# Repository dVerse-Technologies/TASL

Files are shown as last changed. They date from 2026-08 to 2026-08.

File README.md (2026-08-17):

# TASL — modular marble-run engineering challenge

A collaborative marble-run built by ~10 teams of senior engineers. A 25 mm
steel ball travels from a common START to a common FINISH through every team's
module. Battery-powered ESP32 nodes watch the ball with IR break-beams, time
it, and report to a server running a live dashboard over an offline Wi-Fi
network.

Alongside the run there is a simulated materials economy: an operator fires
news events from an admin panel, material prices move, a depot kiosk reprices
and a stage projector flashes breaking news — all on four screens that stay in
sync because one server holds the only copy of the state.

Node schematic

---

## Status

| Step | What | State |
|---|---|---|
| 1 | Live dashboard fed by 3 simulated nodes | **done** |
| 2 | Real ESP32s connected over Wi-Fi | **done — 3 nodes reporting** |
| 3 | IR beam circuit built and range-tested | **done — 40 mm gap working** |
| 4 | Battery sensing + RGB status LED | in progress |
| 5 | Two beams per node, real ball velocity | not started |
| 6 | Replicate across 20 nodes | not started |
| 7 | Admin panel, depot prices, stage projector | **done** |

---

## The four screens

One server on the **Admin MiniPC**, four pages, four machines.

| Machine | URL | Shows | Who sees it |
|---|---|---|---|
| Admin MiniPC | `/admin` | Event triggers, pricing, diagnostics | Operator only |
| Depot MiniPC | `/depot` | Live BOM prices, hike badge top right | Participants |
| Stage laptop + projector | `/stage` | Price board, interrupted by news flashes | The room |
| Build-space MiniPC | `/` | Ball location and speed | Participants |

There are no logins. Screens are separated by URL, and the diagnostics that
used to sit behind a wrench icon on the public dashboard now live on `/admin`
only, so participants never see a station misbehaving.

Sync is not a protocol — it is an absence of one. Every page opens the same
WebSocket and renders the same broadcast, so two boards cannot disagree.

**The full event-day guide is
[`docs/EVENT_DAY_SCREENS.md`](docs/EVENT_DAY_SCREENS.md)** — running order,
kiosk-mode commands, what to press when, and what survives a restart.

---

## Quick start

Two terminals, from the repo root.

```bash
python -m pip install -r requirements.txt
```

**Terminal 1 — dashboard server:**

```bash
python run_server.py
```

**Terminal 2 — three simulated nodes (no hardware needed):**

```bash
python sim/run_mocks.py
```

Then open any of the four screens:

| | |
|---|---|
| <http://localhost:8000/admin> | triggers, pricing, diagnostics |
| <http://localhost:8000/depot> | live material prices |
| <http://localhost:8000/stage> | projector — click **CLICK TO ARM** once |
| <http://localhost:8000/> | ball location and speed |

With real hardware, skip terminal 2 and power the nodes instead.

### Before plugging in hardware

```bash
powershell -ExecutionPolicy Bypass -File tools\preflight.ps1
```

macOS (the event-day machine):

```bash
bash tools/preflight.sh
```

Checks the laptop's IP, firewall, network profile, Wi-Fi band and Python deps.
It changes nothing — it prints the commands you need.

---

## Repo map

```
server/          FastAPI server for all four screens
  protocol.py      THE CONTRACT — exact JSON a node sends. Firmware must match.
  store.py         Node state, run state, SQLite logging
  market.py        Prices, news events, the stage flash. Compounding, rounds up.
  diagnostics.py   Fault rules: what's wrong and what to check
  app.py           HTTP + WebSocket endpoints, the four page routes
  static/          All four UIs (plain HTML/CSS/JS, no build step)
    index.html/app.js    ball tracking      → /
    depot.html           material prices    → /depot
    stage.html/stage.js  projector          → /stage
    admin.html/admin.js  operator console   → /admin
    bus.js               shared WebSocket client for the three new screens
    board.js/board.css   the price board, shared by depot and stage
    media/               drop breaking-news .mp4 clips here (optional)

sim/             Simulated ESP32 nodes — speak the identical protocol
config/
  nodes.json       node registry, order, gap_mm per station
  market.json      the 34 depot lines and the two news events.
                   GENERATED FROM THE BOM — see docs/gameplan/. Never the source.

firmware/
  tasl_node_conn_test/   Main node firmware (Wi-Fi + reporting)
  tasl_beam_align/       Standalone bench tool for aiming the beams
  CONNECTING_NODES.md    Flashing and network setup walkthrough

hardware/
  DECISIONS.md           Why the node is built this way — read this first
  BEAM_CIRCUIT.md        As-built beam circuit, measured values
  NODE_WIRING.md         Original design study and rationale
  schematic-node.svg     Full node schematic
  *.SLDPRT *.STL *.gcode Enclosure CAD and print files

openmarket/      Kasu coin CAD/DXF for the activity's internal economy
tools/
  preflight.ps1 / preflight.sh   pre-event checks (Windows / macOS)
  check_bom.py                   config/market.json vs the BOM. Run after edits.

docs/EVENT_DAY_SCREENS.md   THE event-day guide: four screens, running order
docs/gameplan/              THE SOURCE OF TRUTH for materials, prices and money
  02-BOM/                     master materials list, basekits, procurement
  03-Economy/                 coins, trade rules, God Mode levers
  06-Sizing/                  pipe standardisation, ball and bend physics
  07-Team-Guides/             the printed participant books
  data/                       materials.json, events.json, coins.json, teams.json
EVENT_DAY_MACOS.md          Host setup if a MacBook runs the server instead
```

**Where docs disagree,** [`hardware/DECISIONS.md`](hardware/DECISIONS.md) and
[`hardware/BEAM_CIRCUIT.md`](hardware/BEAM_CIRCUIT.md) win — they record what
was built and measured. `NODE_WIRING.md` is the earlier design study.

---

## Bill of materials

### Per node

| # | Part | Value / spec | Qty | Notes |
|---|---|---|---|---|
| 1 | ESP32 DevKit V1 | 30-pin DOIT | 1 | **Not** the 36-pin DevKitC — pin positions differ |
| 2 | TP4056 module | **with protection** | 1 | Must carry `DW01A` + `8205A`. Without them there's no over-discharge cutoff |
| 3 | MT3608 boost module | adjustable | 1 | **Set to 5.0 V before connecting.** Ships arbitrary, ranges to 28 V |
| 4 | AMS1117-3.3 regulator | 5 V → 3.3 V | 1 | Fed from the boost, never from the cell |
| 5 | 1S LiPo | 3.7 V **1000 mAh** | 1 | 500 mAh works for prototyping only — see DECISIONS D5 |
| 6 | SPST switch | ≥500 mA | 1 | Breaks the plus side only |
| 7 | IR LED, 940 nm | 5 mm, clear | 2 | One per beam. Long leg = anode |
| 8 | IR phototransistor | 5 mm, dark tint | 2 | One per beam. Test which leg is the collector |
| 9 | RGB LED | 5 mm, 4-pin, common cathode, diffused | 1 | Diffused — clear ones are hard to read off-axis |
| 10 | Resistor **220 Ω** | ¼ W | 2 | IR emitter current limit |
| 11 | Resistor **100 kΩ** | ¼ W | 2 | Phototransistor pull-downs. This value is what gives 40 mm range |
| 12 | Resistor 100 kΩ **1%** | ¼ W | 2 | Battery divider — 1% matters, see below |
| 13 | Resistor 330 Ω | ¼ W | 1 | RGB red |
| 14 | Resistor 150 Ω | ¼ W | 2 | RGB green, blue |
| 15 | Capacitor **1000 µF** | electrolytic, 16 V | 1 | Bulk across the 3V3 rail. **Polarised** — stripe to GND |
| 16 | Capacitor 100 nF | ceramic | 2 | One on the ADC divider, one at the ESP32 supply pins |
| 17 | JST-XH 2-pin | male + female | 1 | Battery to board |
| 18 | JST-XH 3-pin | male + female | 2 | One per beam cartridge |
| 19 | Perfboard | | 1 | |

Two values worth not substituting:

- **100 kΩ pull-down (#11).** Measured, not theoretical. It took usable beam
  range from ~5 mm to comfortably past 40 mm. A 10 kΩ only works with the
  parts nearly touching.
- **1% resistors for the divider (#12).** The ratio sets your battery reading
  directly, and 5% parts give ±5% error on a measurement whose entire job is
  distinguishing 3.65 V from 3.80 V.

### Per station (mechanical)

| Part | Spec | Notes |
|---|---|---|
| Steel bearing ball | 25 mm | Bearing-grade |
| PVC pipe | 1½" Schedule 40 | ~40 mm bore; the wall doubles as the light shroud |
| 3D-printed enclosure | PETG | `hardware/*.STL`, gcode included |

### Shared infrastructure

| Part | Notes |
|---|---|
| Wi-Fi router | TP-Link Archer AX53 class. **2.4 GHz SSID must be separate** from 5 GHz — ESP32 cannot see 5 GHz at all |
| Laptop | Runs the dashboard. Fixed IP via DHCP reservation |

---

## How it works

Two HTTP endpoints, both `POST` with a small JSON body:

- `POST /api/heartbeat` — every 2 s, always
- `POST /api/event` — when something happens (`BOOT`, `BALL_PASS`, beam faults)

### The one design rule that matters

**The node computes Δt and speed itself, from its own microsecond clock,
before it touches Wi-Fi.** The laptop never times anything.

```
beam A → micros()  ─┐
beam B → micros()   ├─ all on-node, before the radio is touched
compute Δt, speed  ─┘
                    → then transmit one finished result
```

Wi-Fi latency, packet retries, reconnects and laptop clock drift can only
affect *when a result is displayed*, never the result itself. No NTP, no clock
sync between nodes — each node only ever compares two of its own timestamps.

The simulator in `sim/` speaks this identical protocol, which is why the
dashboard needed no changes when real hardware arrived.

---

## Troubleshooting

The bottom of `/admin` says what's wrong per node and what to check, ordered by
what's quickest and most likely. It distinguishes the cases that matter: a node
that *died* versus one that was *never configured correctly* versus one that's
*online but seeing nothing*.

It is on `/admin` and nowhere else. Participants stand in front of the
build-space dashboard, and a flaky station is the operator's problem, not
theirs — so that screen shows the ball and nothing else.

The **SCREENS** panel on `/admin` is the other half of this: it shows which of
the four displays are actually connected, so "is the projector still alive" is
answered without walking the hall.

---

## Secrets

Wi-Fi credentials and the laptop IP live in `firmware/*/secrets.h`, which is
gitignored. To build the firmware:

```bash
cd firmware/tasl_node_conn_test
cp secrets.example.h secrets.h
```

Then fill in your own values. Never commit `secrets.h`.

---

## Notes on schematics

There is **no KiCad MCP available** in this setup — the connector registry has
no EDA integration, and none is installed. The schematic here is a hand-built
SVG ([`hardware/schematic-node.svg`](hardware/schematic-node.svg)), which is
what the build actually needs: the boards are hand-soldered on perfboard, and
the scarce information is *what connects to what*, not component placement.

If this ever moves to a fabricated PCB, KiCad becomes worth the setup. Until
then the net tables in `BEAM_CIRCUIT.md` and `NODE_WIRING.md` are the
authority.

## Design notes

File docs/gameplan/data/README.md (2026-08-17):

# Machine-readable data

Source of truth for anything built in parallel — the live price display, the trigger panel, the sensor readout.

| File | Contents |
|---|---|
| `materials.json` | Every item: group, MOQ, base/war/tariff price, buyback, basekit total, depot stock, per-team kit quantities |
| `events.json` | God Mode events, multipliers, caps and rules |
| `coins.json` | Denominations, basekit coins, both depot stashes, total mint |
| `teams.json` | Path assignment, per-team challenge and goal, per-team basekit |

## Price model

```
livePrice = base
on "war"    → livePrice = roundUpTo10(livePrice × 1.2)
on "tariff" → livePrice = roundUpTo10(livePrice × 1.3)
```

Both events compound; cumulative effect is ×1.56.

**Buyback never moves.** It is always against `price.base`, never the live price — `buyback.fresh` for unused material, `buyback.modified` for cut but usable. Every base price is a multiple of 20, so `modified` is always payable in coins.

`war` and `tariff` in `materials.json` are pre-computed for display; recompute from `base` if you change the multipliers.

## Regenerating

`materials.json`, `events.json`, `coins.json` and `teams.json` are generated. If quantities or prices change, regenerate rather than hand-editing, so the documents and the data cannot drift.

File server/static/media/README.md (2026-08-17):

# Breaking-news video clips

Drop `.mp4` files here and name them in `config/market.json`:

```json
{ "event_id": "WAR", "video": "war.mp4", ... }
```

The stage projector then plays that clip full-screen on a loop instead of the
built-in news slate. The event's ticker line stays along the bottom; everything
else in the clip is yours.

**A missing file cannot black out the projector.** The server checks this
directory when the event fires; if the named file is not here it logs a line to
the console and sends `null`, and the stage falls back to the built-in animated
slate. So a typo costs you the clip, never the flash.

## What works

- **Container/codec:** `.mp4`, H.264 video, AAC audio. That is what Chrome and
  Edge play without arguing.
- **Resolution:** match the projector, usually 1920×1080. The clip is drawn
  with `object-fit: cover`, so a different aspect ratio is cropped, not
  letterboxed.
- **Length:** a few seconds is right. It loops for the event's
  `flash_seconds` (45 by default), so a 5 s sting plays nine times.

## Sound

The stage page shows a **CLICK TO ARM** prompt when it loads. Click it once
during setup. Browsers refuse to autoplay audio on a page nobody has
interacted with, and without that click every clip plays silently.

If it somehow was not armed, the clip still plays — muted. It never blocks.

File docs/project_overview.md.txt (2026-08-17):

I am designing a modular, large-scale engineering team-building activity: a collaborative marble-run challenge for approximately 10 teams.

PROJECT CONCEPT
Participants are senior engineering professionals. Each team receives a modular challenge section and must design/assemble a marble pathway that connects to other teams' sections. The final system should transport a steel ball from a common START to a common FINISH through all modules.

VENUE
Expected usable area is approximately 3,000 sq ft, potentially a large hall/courtyard. The venue may be roughly 50 ft × 50 ft or similar, but exact dimensions are not yet confirmed.

MARBLE
- Steel bearing balls
- Approximately 25 mm diameter
- Bearing-grade steel preferred
- The marble must roll freely through the pathway.

PATHWAY
Primary pathway material:
- 1½-inch Schedule 40 PVC pipe
- Also potentially 2-inch Schedule 40 PVC
- Pipes will be pre-cut into approximately 1 m sections for transport and participant assembly.
- Clear flexible pneumatic tubing may also be available for visually interesting sections.
- Participants should be able to connect multiple pipe sections without permanent glue.
- Couplers, unions, T-junctions, Y-junctions, 3-way junctions etc. may be used.
- Connections must preserve smooth ball flow and avoid snagging.

STRUCTURE
I initially considered 4040 and 3030 8-mm T-slot aluminium extrusion, pre-cut into 1 m sections, but the cost is proving very high.
I am therefore investigating cheaper structural alternatives such as:
- aluminium angle/channel
- lightweight PVC electrical conduit
- other lightweight modular framing systems.

The structure must be:
- lightweight
- safe for participant handling
- stable
- reusable
- modular
- quick to assemble
- capable of supporting elevated PVC marble pathways.

3D PRINTING
I can 3D-print custom:
- PVC saddle clamps
- pipe holders
- sensor sleeves
- structural connectors
- adapters
- specialized joints

Likely material:
- PETG
- black PETG for sensor housings where useful.

ACTIVITY DESIGN
There will be approximately 10 teams/modules.

Each module should have:
- a defined marble IN point
- a defined marble OUT point
- an engineering challenge
- enough freedom for participants to design their own solution
- standardized interfaces so modules can connect.

The challenge should be genuinely interesting to experienced engineers without requiring precision machining, gears, ratchets or complex mechanisms.

Available construction materials should primarily be:
- PVC pipe
- clear flexible pneumatic tube
- lightweight structural members
- 3D-printed components
- simple fasteners.

ELECTRONICS
I am designing approximately 20 independent ESP32 sensor nodes.

Each module may have two measurement points, with each measurement point consisting of:
- IR LED transmitter
- IR phototransistor receiver

The two optical beams are placed a known fixed distance apart. When the marble breaks each beam, the ESP32 records timestamps.

This allows:
velocity = known distance / time between beam interruptions.

Each sensor node is intended to be:
- self-contained
- battery powered
- enclosed in a small 3D-printed PETG housing
- connected to the venue Wi-Fi
- removable from the physical marble-run.

NETWORK
A TP-Link Archer AX53-class Wi-Fi router will create a local, offline Wi-Fi network.

Approximately 20 ESP32 nodes connect over 2.4 GHz Wi-Fi.

A laptop connects to the same local network.

No Internet connection is required.

The laptop runs the central dashboard/GUI.

The system should continue to work entirely locally even if the WAN/Internet connection is disconnected.

POWER
Each ESP32 node uses a small 1S LiPo battery, approximately:
- 3.7 V nominal
- 500 mAh

Each node should include:
- LiPo charging
- power switch
- battery voltage measurement
- battery status indication.

RGB LED
Each sensor node will have a 5 mm, 4-pin RGB LED, preferably common cathode, although common anode is also acceptable.

Battery status could be:
- Green = healthy
- Yellow = getting low
- Red = low
- flashing red = critically low

The ESP32 should measure LiPo voltage using an ADC and voltage divider.

SENSING
The optical sensor should be a simple IR break-beam system:
IR LED → air gap → phototransistor.

The 25 mm steel ball interrupts the beam.

Avoid TV-remote-style 38-kHz IR receiver modules; use a bare IR emitter + phototransistor arrangement.

GUI
The central laptop dashboard should display:
- modules/nodes
- ball detected
- ball passed
- timestamps
- measured velocity where appropriate
- node battery status
- connectivity/heartbeat status
- potentially overall elapsed time.

DESIGN PHILOSOPHY
This is an engineering leadership/team-building event rather than a commercial production machine.

Prioritize:
1. Safety
2. Reliability
3. Ease of participant assembly
4. Fast setup/reset
5. Reusability
6. Low cost
7. Clear measurement
8. Interesting engineering constraints.

I want you to act as a systems engineer and help me develop the complete architecture.

Please provide:
1. Overall system architecture
2. Physical modular architecture
3. Standardized module interfaces
4. Recommended structural material
5. PVC pathway connection strategy
6. Sensor architecture
7. ESP32/network architecture
8. Power architecture
9. Battery monitoring strategy
10. GUI/dashboard architecture
11. Recommended event workflow
12. Safety considerations
13. A practical prototype plan for building and testing 3 modules first
14. Major technical risks and how to mitigate them
15. A final recommended architecture that balances cost, reliability and participant experience.

Do not assume aluminium T-slot extrusion is mandatory. Challenge that assumption if a cheaper/lightweight solution is better.

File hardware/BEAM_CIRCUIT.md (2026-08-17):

# IR beam circuit — as built and tested

Values below are the ones that actually worked on the bench at a 40 mm beam
gap, not the theoretical values in NODE_WIRING.md §8.

| Part | Value | Colour code |
|---|---|---|
| IR emitter current limit | **220 Ω** | red, red, brown, gold |
| Phototransistor pull-down | **100 kΩ** | brown, black, yellow, gold |

The 100 kΩ pull-down is what took the range from ~5 mm to comfortably past
40 mm. A 10 kΩ works only with the parts almost touching.

---

## One beam

```
   +3V3 ────┬──────────────────────────────┐
            │                              │
         [220 Ω]                           │
            │                              │
            │  long leg (anode)            │  COLLECTOR
            ▼                              ▼
         ┌─────┐                        ┌─────┐
         │ IR  │  ) ) )  40 mm  ( ( (   │photo│
         │ LED │ ──────────────────────>│trans│
         └─────┘                        └─────┘
            │  short leg (cathode)          │  EMITTER
            │                              │
            │                              ├──────────> GPIO
            │                              │
            │                          [100 kΩ]
            │                              │
   GND  ────┴──────────────────────────────┴────

   Beam clear   -> phototransistor conducts -> GPIO reads HIGH
   Beam blocked -> phototransistor off      -> GPIO pulled LOW
```

A ball passing is a **falling edge**.

---

## Power — AMS1117 + 1000 µF

```
  LiPo      TP4056     SPST      MT3608        AMS1117-3.3
 1000mAh   +protect   switch   boost to 5.0V    regulator
    │         │         │          │                │
    ●─────────●─────────●──────────●────────────────●──────┬──── +3V3 rail
                                                           │
                                                     [1000 µF 16V]
                                                           │
   GND ────────────────────────────────────────────────────┴──── GND
```

The +3V3 rail feeds the **ESP32 `3V3` pin**, both IR emitters and both
phototransistors.

### Three things that will destroy a board if you get them wrong

**The AMS1117 must be fed from the 5 V boost, never from the LiPo.** It needs
about 1.1 V of dropout, so at least 4.4 V in to give 3.3 V out. A 3.7 V cell
straight into it produces roughly 2.6 V and the ESP32 will not run —
that is the same brownout that took NODE02 offline.

```
5.0 V in − 3.3 V out = 1.7 V headroom   ✓  (needs > 1.1 V)
```

**Feeding the `3V3` pin bypasses the ESP32's onboard regulator.** That is the
point — it is why the sensors get a clean rail. But it means `VIN` must be left
unconnected, and the **switch must be OFF before you plug in USB**, every time.

**The 1000 µF is polarised.** Its negative stripe goes to GND. Backwards, it
vents. It sits across the 3V3 rail as close to the ESP32 as you can get it, and
it is what absorbs the ~250 mA current spike each Wi-Fi transmit draws.

A 100 nF ceramic in parallel with it, right at the ESP32 pins, is worth adding
if you have one — the electrolytic is too slow for high-frequency noise.

### Heat

The AMS1117 burns the difference as heat:

```
(5.0 − 3.3) V × 0.15 A ≈ 0.26 W
```

Warm to the touch is normal. Too hot to hold means something is drawing far
more than it should — switch off and find it before it fails.

---

## Both beams on one node

```
                    ESP32 DevKit V1
                   ┌─────────────────┐
   +3V3 rail ──────┤ 3V3             │
       GND ────────┤ GND             │
                   │                 │
   beam A sig ─────┤ D19             │
   beam B sig ─────┤ D18             │
                   │                 │
   batt divider ───┤ D34             │
                   │                 │
        (unused) ──┤ VIN             │   ← leave disconnected
                   └─────────────────┘
```

Beam A and beam B are **electrically identical**. Build one, test it, then
build the second the same way.

---

## Connection table

Repeat every row for beam B, substituting **D18** for **D19**.

| From | To |
|---|---|
| `3V3` | 220 Ω, leg 1 |
| 220 Ω, leg 2 | IR LED **long leg** (anode) |
| IR LED **short leg** (cathode) | `GND` |
| `3V3` | phototransistor **collector** |
| phototransistor **emitter** | `D19` |
| phototransistor **emitter** | 100 kΩ, leg 1 |
| 100 kΩ, leg 2 | `GND` |

---

## Mounting through the PVC pipe

- Drill **5 mm holes directly opposite** each other, on the same axis.
- Beam sits **~12 mm up from the inner floor** — a 25 mm ball in a 40 mm pipe
  rolls along the bottom, so that height is its centre and it always blocks
  fully.
- Push both parts in **flush with the inner wall**. Anything protruding gets
  hit by the ball.
- Hot glue from the outside.

The pipe wall doubles as the ambient-light shroud, which is what makes the
sensitive 100 kΩ pull-down safe to use.

---

## gap_mm

The distance between **beam A and beam B** along the pipe — not the 40 mm
across it. Measure it on the finished assembly and record it in
`config/nodes.json` and in that node's firmware.

`speed = gap_mm / Δt`, so a 2 mm error is a 2% error on every reading that
station ever produces, and nothing downstream can detect it.

---

## Pin note

D19 and D18 are digital-only — they are **not** ADC pins. `analogRead()` will
not work on them, so the beam-align sketch runs in digital mode
(`BEAM_ANALOG 0`). Ball timing only needs digital edges, so nothing is lost.

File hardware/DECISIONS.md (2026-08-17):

# Hardware decision log

Why the node is built the way it is. Each entry records the decision, the
reasoning, and what it replaced — so a choice that looks arbitrary six months
from now can be re-examined against the reason it was made.

Where this file and [`NODE_WIRING.md`](NODE_WIRING.md) disagree, **this file
and [`BEAM_CIRCUIT.md`](BEAM_CIRCUIT.md) win** — they record what was actually
built and measured. `NODE_WIRING.md` is the original design study and still
holds the rationale for the parts that didn't change.

---

## D1 — ESP32 DevKit V1 (30-pin DOIT)

**Decided:** the 30-pin DOIT DevKit V1, not the 36-pin DevKitC.

Pin *positions* differ between the two, so every wiring table in this repo is
specific to the 30-pin board. Substituting a DevKitC without re-checking the
pinout will put the beams on the wrong pins.

Constraints that follow and drive everything else:

- **ADC2 is unusable.** It shares hardware with the Wi-Fi radio and stops
  returning valid readings the moment Wi-Fi is up. Every analog input must be
  on **ADC1** (GPIO32–39). A battery divider on ADC2 tests perfectly on the
  bench and reads zero in the field.
- **GPIO6–11** are wired to the onboard SPI flash. Using them prevents boot.
- **GPIO34–39** are input-only with no internal pull-ups — fine for the ADC,
  useless for driving anything.
- The onboard **AMS1117** needs ~1.1 V of dropout, which rules out feeding
  `VIN` from a LiPo (see D2).

---

## D2 — Power: LiPo → TP4056 → switch → MT3608 → AMS1117 → `3V3` pin

**Decided:** boost the cell to 5 V, regulate back down to 3.3 V externally, and
feed the ESP32's **`3V3` pin** directly. `VIN` is left unconnected.

```
LiPo ──> TP4056 ──> SPST ──> MT3608 ──> AMS1117-3.3 ──┬──> +3V3 rail
1000mAh  +protect   switch   boost 5V    regulator     │
                                                  [1000 µF]
GND ───────────────────────────────────────────────────┴──> GND
```

**Superseded:** the earlier plan fed the MT3608's 5 V straight into `VIN` and
let the onboard regulator make 3.3 V.

**Why it changed:** the sensors want a clean rail that isn't sharing the
onboard regulator with the ESP32's own transient load. Feeding `3V3` from an
external AMS1117 gives both the MCU and the optics a quieter supply. **NODE02
browning out** during testing is what prompted the change.

**Why not simpler options:**

| Option | Why it fails |
|---|---|
| LiPo → `VIN` | AMS1117 needs ≥4.4 V in. A cell starts at 4.2 V and falls. Brownout immediately. |
| LiPo → `3V3` | `3V3` sits on the 3.3 V rail. A charged cell at 4.2 V is 0.9 V over rating — damages the board. |
| LM2596 buck, 3.7 → 3.3 V | Datasheet minimum input is **4.5 V**; a 3.7 V cell is already below it. And no buck makes 3.3 V from a cell sagging to 3.0 V. It also idles at 5–10 mA. |
| AMS1117 fed straight from the LiPo | Same dropout problem: 3.7 V in gives ~2.6 V out. This was the NODE02 brownout. |

**Consequences that must be respected:**

- `VIN` stays **disconnected**. Feeding both `VIN` and `3V3` fights the onboard
  regulator.
- **Switch OFF before plugging in USB**, every time. The switch sits before the
  boost so that switching off fully disconnects the battery supply.
- The **1000 µF is polarised** — negative stripe to GND. Backwards, it vents.
  It absorbs the ~250 mA spike on each Wi-Fi transmit.
- The AMS1117 dissipates `(5.0 − 3.3) × 0.15 ≈ 0.26 W`. Warm is normal; too hot
  to hold means something is drawing far more than it should.

---

## D3 — Every MT3608 is set to 5.0 V before it is connected

**Decided:** adjust and lock every boost module on the bench, before it ever
touches an ESP32.

MT3608 modules are adjustable and ship at an **arbitrary** setting, with a
range up to 28 V. Connecting an unadjusted one destroys the board instantly.

Procedure: power the input from a cell → **nothing on the output** → meter the
output pads → turn the multi-turn pot to **5.0 V** → disconnect → then wire it
in → lock the pot with nail varnish.

---

## D4 — TP4056 **with protection** (DW01A + 8205A)

**Decided:** only the protected variant.

The bare TP4056 has no over-discharge cutoff and will flatten a LiPo until it
is damaged and potentially unsafe. The protected board carries **three** ICs:
`TP4056`, `DW01A` (6-pin, near `B−`), and `8205A` (8-pin dual MOSFET). If the
board has only the TP4056 chip, it is the wrong part.

The battery connects to `B+`/`B−` and **nothing else** — the protection sits
between `B` and `OUT`, so tapping the cell directly bypasses it.

Charging goes through `IN`/`B` and does not pass through the switch, so
**charging works with the node switched off**.

---

## D5 — Battery: 1000 mAh for production, 500 mAh for prototyping

**Decided:** 1000 mAh 1S LiPo for the 20-node build. The 3× 500 mAh cells on
hand are fine for prototyping.

The event runs **4 hours**, but nodes are powered for longer — setup, teams
building, dry runs, teardown. Design for **~6 hours of switch-on time**.

| Cell | Worst case | Likely | With firmware wins |
|---|---|---|---|
| 500 mAh | 2.8 h | 4.5 h | ~6.5 h |
| **1000 mAh** | **5.5 h** | **9 h** | **~13 h** |
| 2000 mAh | 11 h | 18 h | ~26 h |

1000 mAh clears the requirement even in the worst case, and needs **no TP4056
modification** — stock 1000 mA charge is 1C. A 500 mAh cell would be charged at
2C and need `R_prog` changed on all 20 modules.

**Rejected: 2× 500 mAh in parallel.** Electrically fine, but 40 cells, 40 extra
joints, larger total volume, usually more cost, and a voltage-matching step
repeated 20 times. Cells joined at differing charge can pass several amps
between themselves — the standard way people get hurt paralleling LiPos.

**Still to measure:** actual current draw. Every figure above is calculated. A
multimeter in series with the battery settles it in ten minutes.

---

## D6 — Beam values: 220 Ω emitter, 100 kΩ pull-down

**Decided:** 220 Ω IR emitter current limit, **100 kΩ** phototransistor
pull-down, at a 40 mm beam gap across the pipe.

**Superseded:** the theoretical 100 Ω / 10 kΩ in `NODE_WIRING.md §8`.

**Why it changed:** measured on the bench. The **100 kΩ pull-down took usable
range from ~5 mm to comfortably past 40 mm.** A 10 kΩ only works with the parts
almost touching — useless across a 40 mm pipe.

The higher pull-down makes the receiver more sensitive, which would normally
raise ambient-light risk. It is safe here because **the pipe wall itself is the
shroud** (D7).

Beam clear → phototransistor conducts → GPIO **HIGH**.
Ball blocks it → 100 kΩ pulls it **LOW**. A ball passing is a **falling edge**.

---

## D7 — Sensors mount through the pipe wall

**Decided:** 5 mm holes drilled directly opposite each other, parts pushed
flush with the inner wall, hot-glued from outside. Beam sits **~12 mm up from
the inner floor**.

A 25 mm ball in a ~40 mm pipe rolls along the bottom, so 12 mm is its centre
line and it always blocks the beam fully.

Flush mounting is not cosmetic — anything protruding into the bore gets struck
by the ball.

The pipe wall doubling as an ambient-light shroud is what makes the sensitive
100 kΩ pull-down viable (D6), and removes the need for separate 3D-printed
shrouds.

---

## D8 — Beams on D19 / D18, battery on D34

**Decided:**

| GPIO | Function | Note |
|---|---|---|
| `D19` | Beam A signal | digital only |
| `D18` | Beam B signal | digital only |
| `D34` | Battery sense | ADC1, input-only |

**Superseded:** GPIO32/33 for beams in the original plan.

**Trade-off accepted:** D19 and D18 are **not** ADC pins, so `analogRead()`
does not work on them and the alignment sketch runs in digital mode
(`BEAM_ANALOG 0`). Ball timing only needs digital edges, so nothing is lost for
the measurement — but fine aiming by raw analog level is no longer available on
those pins.

`D34` must stay on ADC1 (D1).

---

## D9 — No comparator, for now

**Decided:** phototransistor straight into the GPIO, with debouncing handled in
firmware. No LM393.

A comparator gives crisper edges and better ambient-light immunity, but adds a
trimpot per beam — **40 trimpots to calibrate** across 20 nodes.

The dashboard's troubleshooting panel reports **"Implausible speed recorded"**
and **"Beam A triggered without beam B"**. If a station keeps reporting those
after alignment is confirmed, add an LM393 to *that station*. The decision is
deferred until there is evidence, rather than paying the calibration cost up
front on a guess.

---

## D10 — Velocity is computed on the node, never on the laptop

**Decided:** each node times both beams against its own `micros()` clock,
computes Δt and speed, and transmits one finished measurement.

```
beam A → micros()  ─┐
beam B → micros()   ├─ all on-node, before the radio is touched
compute Δt, speed  ─┘
                    → then transmit
```

**Why:** Wi-Fi latency, packet retries, reconnects and laptop clock drift can
then only affect *when a result is displayed*, never the result itself. It also
removes any need for NTP or clock sync between nodes — each node only ever
compares two of its own timestamps.

This is why Wi-Fi modem sleep can be left on: it delays inbound traffic, which
this design never depends on.

---

## D11 — `gap_mm` is measured, not assumed

**Decided:** the beam A → beam B spacing is measured on each finished assembly
and recorded per station in `config/nodes.json` and in that node's firmware.

`speed = gap_mm / Δt`, so a 2 mm error over a 100 mm gap is a **2% error on
every reading that station ever produces** — and nothing downstream can detect
it. It is the one number in the system with no error-checking behind it.

Note it is the spacing **along** the pipe, not the ~40 mm across it.

---

## Open items

| Item | Needed before |
|---|---|
| Measure real current draw with a multimeter | ordering 20 cells |
| Confirm `WiFi.setSleep(true)` and `setCpuFrequencyMhz(80)` savings | firmware freeze |
| Calibrate ADC per board against a multimeter | battery thresholds are trustworthy |
| Decide RGB LED common cathode vs anode from the parts in hand | LED wiring is soldered |
| Measure `gap_mm` per station | any speed reading is meaningful |

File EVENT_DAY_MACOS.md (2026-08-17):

# Event day — running the server on a MacBook

> **The plan of record is that the Admin MiniPC runs the server**, not the
> MacBook — see [`docs/EVENT_DAY_SCREENS.md`](docs/EVENT_DAY_SCREENS.md). This
> document is the macOS host setup, kept for the case where a MacBook has to
> take over. Everything below about the fixed IP applies to whichever machine
> holds the server role.

Development happens on the Windows PC.

The good news: nearly all the Windows pain doesn't exist on macOS. There's no
Public/Private network category, and no "Unidentified network" trap on a
WAN-less router. The bad news is one new gotcha and one genuinely important
decision.

---

## The important decision: fix the server IP now

`SERVER_IP` is **compiled into every node's firmware**. Right now it's
`192.168.1.37` — the Windows PC's address.

If the MacBook gets a different address on event day, **every node silently
fails and you'd have to reflash all ~20 of them on site.** That is the single
worst failure this project can have, and it's entirely avoidable.

**Pick one server address and make whichever machine runs the server take it.**

Suggested: whatever subnet the Archer AX53 uses, pick something clearly outside
its DHCP pool, e.g. `192.168.0.50`.

Then:

1. Put that address in the firmware and flash all nodes with it — once, here.
2. On the **MacBook**, set that address manually:
   **System Settings → Network → Wi-Fi → Details → TCP/IP →
   Configure IPv4: Manually**, IP `192.168.0.50`, subnet `255.255.255.0`,
   router = the Archer's address.
3. On the **Windows PC**, set the same address when *it* runs the server, so
   development and event day are identical.

Only one machine holds that address at a time, which is exactly right — only
one runs the server.

Doing this means the firmware never changes between now and event day.

> Alternative: I can add mDNS to the firmware so nodes resolve `tasl.local`
> instead of a hard IP. Bonjour is native on macOS so it works well, but it
> adds a failure mode that a fixed IP doesn't have. Ask if you'd prefer it.

---

## Setting up the MacBook

### 1. Python

macOS doesn't ship a usable Python 3. Install from
[python.org](https://www.python.org/downloads/macos/), or with Homebrew:

```bash
brew install python
```

Check:

```bash
python3 --version
```

### 2. Copy the project across

Copy the whole `TASL` folder. Then:

```bash
cd ~/TASL
python3 -m pip install -r requirements.txt
```

### 3. Preflight

```bash
bash tools/preflight.sh
```

The macOS equivalent of `preflight.ps1`. It reports the Mac's LAN IP, firewall
state, Wi-Fi band, Python deps and whether the server is up — and tells you if
the IP doesn't match what's in your firmware.

### 4. Run it

```bash
python3 run_server.py
```

Open <http://localhost:8000>.

---

## The one macOS gotcha: the firewall prompt

macOS's firewall is **per-application**, not per-port. There's no rule to add.

The first time you run the server, macOS may show:

> *"Do you want the application python3 to accept incoming network
> connections?"*

**Click Allow.** If you click Deny — or the dialog appears behind a window and
gets dismissed — every node fails silently and the dashboard shows all
stations OFFLINE with no clue why.

To check or fix afterwards:
**System Settings → Network → Firewall → Options** — make sure `python3` is
listed and set to *Allow incoming connections*.

Also confirm **"Block all incoming connections" is OFF**. It overrides
everything else, and the preflight script flags it.

If the firewall is off entirely (the default on many Macs), there's nothing to
do at all.

---

## Flashing ESP32s from the Mac

Only needed if you have to reflash on site — which the fixed-IP plan above is
designed to avoid.

- Arduino IDE setup is identical: same boards-manager URL, same
  **DOIT ESP32 DEVKIT V1** board.
- Ports appear as `/dev/cu.usbserial-xxxx`, `/dev/cu.SLAB_USBtoUART` or
  `/dev/cu.wchusbserial-xxxx` instead of `COM3`.
- Pick the `cu.*` entry, not the `tty.*` one.
- **CP2102** boards work with no driver on modern macOS. **CH340/CH9102**
  boards usually need the WCH driver — and on Apple Silicon you need the
  current signed version, older ones won't load.

Worth confirming *before* event day that the Mac can see a board at all, even
if you never plan to use it. Ten minutes now versus a dead end on site.

---

## Event day running order

1. Power the Archer AX53. Wait for it to come up fully.
2. Join the MacBook to the **2.4 GHz** SSID.
3. Confirm the Mac has the agreed static IP.
4. ```bash
   bash tools/preflight.sh
   ```
   Everything must say READY before you power a single node.
5. ```bash
   python3 run_server.py
   ```
6. Open <http://localhost:8000>. Allow the firewall prompt if it appears.
7. Bring up the other three screens — see
   [`docs/EVENT_DAY_SCREENS.md`](docs/EVENT_DAY_SCREENS.md).
8. Power the nodes. Watch them turn ONLINE one at a time.
9. Any that don't: the diagnostics panel at the bottom of `/admin`.

---

## What differs from Windows, in one table

| | Windows (dev) | macOS (event) |
|---|---|---|
| Preflight | `tools\preflight.ps1` | `tools/preflight.sh` |
| Run server | `python run_server.py` | `python3 run_server.py` |
| Firewall model | Per-port rule | Per-application allow |
| Network category | Public/Private — a real trap | Doesn't exist |
| WAN-less network | Flags as Public every time | No such behaviour |
| Serial port | `COM3` | `/dev/cu.usbserial-*` |

The server, dashboard, protocol, diagnostics and firmware are identical on
both. Only the host setup differs.

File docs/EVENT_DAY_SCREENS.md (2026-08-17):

# Event day — the four screens

One server, four pages, four machines. Everything is in sync because there is
only ever one copy of the state: the server holds it, and every screen renders
the same broadcast.

```
                    Archer AX53 (offline, 2.4 GHz)
                               │
        ┌──────────────┬───────┴───────┬──────────────┐
        │              │               │              │
   ADMIN MiniPC   Depot MiniPC   Stage laptop   Build-space MiniPC
   runs server         │          + projector          │
        │              │               │              │
     /admin         /depot          /stage             /
                               ▲
                     ~20 ESP32 nodes ──┘  POST to the ADMIN MiniPC's IP
```

| Machine | URL | Who looks at it |
|---|---|---|
| Admin MiniPC | `/admin` | Operator only |
| Depot MiniPC | `/depot` | Participants buying materials |
| Stage laptop → projector | `/stage` | The whole room |
| Build-space MiniPC | `/` | Participants building |

Replace `<SERVER_IP>` below with the admin machine's address, e.g.
`http://192.168.0.50:8000/depot`.

---

## The one thing to get right first: the server IP

`SERVER_IP` is **compiled into every node's firmware**. The nodes do not care
which machine answers — only which *address* answers.

So moving the server to the Admin MiniPC does **not** mean reflashing anything.
Give the Admin MiniPC the address the firmware already points at, and every
node connects exactly as before.

1. Find the address currently in `firmware/tasl_node_conn_test/secrets.h`.
2. Assign that address statically to the **Admin MiniPC**.
3. Make sure no other machine holds it. Only one machine runs the server.

Reflashing is only needed if you cannot give the Admin MiniPC that address —
and if you find yourself in that position, the cheaper fix is a DHCP
reservation on the Archer, not twenty boards over USB.

---

## Running order

1. Power the Archer AX53. Wait for it to come up fully.
2. Join all four machines to the **2.4 GHz** SSID.
3. On the Admin MiniPC, confirm it holds the agreed static IP, then:

   ```bash
   python run_server.py
   ```

4. Open each screen. Kiosk-mode command lines are below.
5. **Click the CLICK TO ARM prompt on the stage projector.** One click, once.
   Browsers refuse to autoplay audio on a page nobody has touched, and without
   it every news clip plays silently.
6. Power the nodes. Watch them come ONLINE in the admin panel's diagnostics.
7. On `/admin`, check the **SCREENS** panel: all four pips green before you
   start. That is your proof every display is actually listening, without
   walking the hall.

### Kiosk-mode launch

Chrome or Edge, on each display machine:

```bash
chrome --kiosk --noerrdialogs --disable-session-crashed-bubble --incognito http://<SERVER_IP>:8000/depot
```

Swap the path per machine: `/depot`, `/stage`, `/` and `/admin`. `F11` also
works if you would rather not use flags. Press `Alt+F4` to leave kiosk mode.

---

## Firing an event

On `/admin`, under **NEWS TRIGGERS**:

1. Press **FIRE WAR**. The button changes to **CONFIRM — FIRE**.
2. Press it again within four seconds.

At that instant, on every screen at once: prices rise, the depot's hike badge
jumps to `×1.2`, and the projector takes over with the breaking-news flash for
45 seconds before returning to the price board.

Then at the 2:00 mark, the same with **FIRE TARIFF** — the board goes to `×1.56`.

**Firing twice never doubles the price change.** A second press only replays
the flash. This is deliberate: under stage lighting a double-tap is far more
likely to be nerves than a second war.

### If something goes wrong

| Problem | Fix |
|---|---|
| Fired the wrong event | **UNDO PRICE CHANGE** on that trigger. Reverses everywhere immediately. |
| Flash needs to go away now | **DISMISS FROM STAGE** in the red strip at the top. |
| Nobody was looking | **REPLAY ON STAGE**. Re-shows the flash, does not touch prices. |
| Need an unplanned price move | **MANUAL ADJUSTMENT** — a percentage across every item. Or a single item's own % in the pricing table. |
| Rehearsing before the event | **RESET MARKET TO BASE** clears everything back to base prices. |

---

## The pricing math

Each event multiplies the price **already on the board** and the result is
rounded **up** to the nearest 10 before the next event is applied:

```
price = base
on WAR    → price = ceil10(price × 1.2)
on TARIFF → price = ceil10(price × 1.3)
then      → price = ceil10(price × (1 + (manual adjustment + this item's %)/100))
```

War then Tariff gives **×1.56**, not ×1.50. This is the model in
[`docs/gameplan/data/README.md`](gameplan/data/README.md), which is what the
BOM's war and tariff columns and the printed team guide books are computed
from. The board has to agree with the books.

Rounding up between the steps is the whole reason 25mm pipe goes
`60 → 80 → 110` rather than `60 → 72 → 94`. Prices round to 10 because the
coins in `openmarket/` are 10/20/50/100/500 and a price of 85 cannot be paid.

> **Individual rows move by more than 56%, and by different amounts.** 25mm
> pipe at 60 ends up +83%, 32mm pipe at 200 ends up +60%. That is rounding up
> on a cheap item, not a bug. The `×1.56` on the badge is the announced figure
> and is true of every line before rounding; the per-row percentage on `/admin`
> is what that row actually charges.

**Buyback never moves.** It is always against the **base** price — full for
unused material, half for cut-but-usable, nothing for unusable. If buyback
tracked the live price, a team could stockpile before the war announcement and
sell back at wartime prices for risk-free profit.

---

## What survives what

| | Fired events & prices | Ball progress & timer | SQLite event log |
|---|---|---|---|
| **RESET** (marble run) | kept | cleared | kept |
| **RESET MARKET TO BASE** | cleared | kept | kept |
| **Server restart** | **kept** | cleared | kept |
| **Reloading a screen** | kept | kept | kept |

Market state is written to `data/market_state.json` on every change and
reloaded on boot. If the server is restarted at the 1:45 mark, War is still
fired when it comes back — that is not information recoverable any other way.

---

## Diagnostics moved

The wrench icon is gone from the build-space dashboard. Troubleshooting now
lives at the bottom of `/admin` only, so participants standing in front of the
build-space monitor never see a station misbehaving. The rules and explanations
are unchanged.

---

## Editing the event

Everything lives in [`config/market.json`](../config/market.json): the 34
sellable BOM lines with their groups, base prices, buyback and stock counts,
plus the two events with their headlines, tickers and percentages. Restart the
server after editing.

**That file is generated from the BOM, not authored.** The names, prices,
buyback and quantities all come from
[`docs/gameplan/data/materials.json`](gameplan/data/materials.json), which is
generated in turn from
[`docs/gameplan/02-BOM/master-materials-and-mint.md`](gameplan/02-BOM/master-materials-and-mint.md).
If a number disagrees, the BOM wins — fix `config/market.json` to match, not
the other way round. `item_id` is the BOM's own id so the two can be diffed
line for line. To check they still agree:

```bash
python tools/check_bom.py
```

`item_id` and `event_id` are the keys state is stored against —
**do not change them once the event has started.** Names, prices and headlines
are safe to edit any time before.

The depot board shows buyback but deliberately **not** stock counts: a visible
count turns a shortage into a race. Stock is on `/admin` only.

To use your own news clips, drop `.mp4` files into `server/static/media/` and
name them in the event's `video` field. See
[`server/static/media/README.md`](../server/static/media/README.md). A missing
file falls back to the built-in animated slate, so a typo costs you the clip
and never blacks out the projector.

---

## Troubleshooting the screens

**A screen shows OFFLINE / a red veil.** It has lost the WebSocket. It retries
on its own, backing off to every 5 seconds, forever — no need to touch it. If
it stays red: check that machine's Wi-Fi, then that the server is still running
on the Admin MiniPC.

**A screen shows stale prices.** It cannot, unless it is disconnected — in
which case the veil is up saying so. There is one copy of the state and every
screen renders the same broadcast.

**Prices look wrong.** Check the **MARKET LOG** on `/admin`. Every fire, undo,
manual adjustment and reset is timestamped there.

**The projector went black.** The flash never blacks out — a missing video
falls back to the slate. A black projector is the projector's input, sleep
settings, or the cable. Disable screen sleep on the stage laptop before you
start.

**A news clip plays silently.** The CLICK TO ARM prompt was never clicked.
Reload `/stage` and click it.

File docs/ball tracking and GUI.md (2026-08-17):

I am designing the sensing and live-monitoring subsystem for a large modular marble-run engineering challenge.

Design ONLY the sensing, ESP32 communication and laptop GUI architecture.

PHYSICAL SYSTEM

Approximately 10 modules will be connected together.

Steel bearing ball:
- approximately 25 mm diameter.

Each measurement station has TWO optical break-beam points separated by a precisely known distance.

Example:

IR beam A                 IR beam B
    │                         │
    ▼                         ▼
    ●─────────────────────────●
             100 mm

             ↓
          steel ball

When the marble interrupts Beam A:
- record timestamp t1.

When it interrupts Beam B:
- record timestamp t2.

Then:

velocity = distance / (t2 - t1)

Each measurement station therefore provides:
- ball detected at entry
- ball detected at exit
- elapsed time
- calculated velocity.

SENSOR HARDWARE

Each beam consists of:
- 940 nm IR LED emitter
- bare IR phototransistor receiver

Do NOT use a 38 kHz TV-remote receiver module.

The sensor should be designed as a 3D-printed PETG sleeve/cartridge that mounts around/onto the PVC pathway.

The sensor should:
- be removable
- be repeatable
- align emitter and receiver reliably
- shield the receiver from ambient light
- work indoors and outdoors
- detect a 25 mm steel ball reliably.

Discuss:
- optical geometry
- aperture size
- sensor spacing
- ambient-light rejection
- pull-up resistor
- IR LED current limiting resistor
- phototransistor circuit
- whether comparator/Schmitt trigger is needed
- whether ESP32 ADC or digital GPIO should read the detector
- debounce/noise filtering
- false-trigger prevention.

ESP32

There will be approximately 20 ESP32 nodes.

The goal is to keep each sensor node self-contained and battery powered.

The ESP32 nodes connect over a local 2.4 GHz Wi-Fi network.

Router:
- TP-Link Archer AX53-class router
- no Internet required.

Laptop:
- connected to the same local network
- runs the central dashboard.

The network must work entirely offline.

NETWORK ARCHITECTURE

Design a robust architecture for approximately 20 ESP32 nodes.

Compare:
- HTTP
- WebSocket
- MQTT
- UDP
- TCP

Recommend the simplest reliable solution for this event.

The sensor event data is extremely small.

Each ESP32 should identify itself with a unique node ID, e.g.:

NODE01
NODE02
...
NODE20

Each event should contain at minimum:
- node ID
- sensor ID
- event type
- timestamp
- battery voltage
- Wi-Fi/connectivity status.

TIME SYNCHRONIZATION

This is important.

The laptop needs to calculate/display timing accurately enough for measuring marble velocity.

Explain:
- whether ESP32 local timestamps are sufficient
- whether NTP is suitable on a local router
- whether laptop time synchronization is required
- whether velocity should be calculated locally on each ESP32 rather than relying on laptop timestamps.

I suspect the ESP32 should calculate the interval between Beam A and Beam B locally because both sensors belong to the same node.

Evaluate this.

GUI

The laptop should have a live dashboard.

For each module/sensor station, display:

- NODE ID
- status: ONLINE/OFFLINE
- ball detected
- last ball timestamp
- measured time between beams
- calculated velocity
- battery state
- battery voltage
- communication health.

When a ball passes:

Example:

NODE03
BALL DETECTED
Time: 14:32:17.245
Δt: 0.842 s
Speed: 0.119 m/s
Battery: GREEN

The GUI should make the event visually obvious so there is no ambiguity about whether a ball actually passed a station.

I also want:
- event log
- timestamped records
- ability to reset/start a run
- overall elapsed event time
- module-by-module ball progression.

Potentially:

START → Module 1 → Module 2 → ... → Module 10 → FINISH

The system should detect where the ball currently is.

Please recommend a simple technology stack for the laptop GUI that is easy to build and deploy for an event.

For example:
- Python
- Flask/FastAPI
- WebSocket
- SQLite
- browser-based dashboard

Evaluate whether this is preferable to a native desktop application.

IMPORTANT CONSTRAINTS

This is a live event, so prioritize:

1. Reliability
2. Deterministic sensing
3. Simple debugging
4. Offline operation
5. Clear visualization
6. Minimal latency
7. Easy replacement of a failed ESP32 node
8. No dependence on cloud services
9. No Internet requirement.

Please provide:

1. Complete sensor circuit
2. Recommended components and values
3. ESP32 GPIO allocation
4. Sensor firmware architecture
5. Event packet/message format
6. Network architecture
7. Time synchronization strategy
8. Local velocity calculation strategy
9. Laptop server architecture
10. GUI layout
11. Data model
12. Fault handling
13. Offline startup procedure
14. Testing procedure for 1 node
15. Testing procedure for 20 nodes
16. Recommended final architecture.

Be technically rigorous but avoid unnecessary complexity. The goal is a robust event prototype that can later be replicated across 20 sensor nodes.

IMPORTANT ARCHITECTURAL PREFERENCE

For the ball-pass system, strongly consider calculating speed locally on the ESP32.

The preferred flow is:

Beam A → ESP32 timestamp → Beam B → ESP32 timestamp → calculate Δt → calculate speed → send one completed event to laptop.

Wi-Fi latency should NOT affect the actual speed measurement.

The laptop should receive the completed measurement and display/log it.

Also explain how the ESP32 should handle:
- a Beam B trigger without a preceding Beam A trigger
- multiple triggers caused by one ball
- a ball stopping between the two beams
- a second ball arriving too quickly
- sensor noise
- Wi-Fi temporarily disappearing
- ESP32 rebooting
- low battery.

Recommend sensible timeout, debounce and state-machine logic for these cases.

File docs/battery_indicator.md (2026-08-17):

I am building a battery-powered ESP32 sensor node for a modular marble-run engineering challenge.

I want you to design ONLY the electronics/power subsystem described below. Do not redesign the physical marble-run.

NODE
Each sensor node contains:
- ESP32-WROOM-32-class development board
- 1S LiPo battery
- approximately 3.7 V nominal, 500 mAh
- IR LED + IR phototransistor sensor
- 5 mm 4-pin RGB LED
- Wi-Fi connectivity
- power ON/OFF switch.

The node is enclosed in a small 3D-printed PETG enclosure.

POWER REQUIREMENTS
The LiPo should:
- power the ESP32 safely
- be rechargeable
- have appropriate protection
- be replaceable if necessary.

I want an onboard charging solution.

Please design a practical circuit using inexpensive, readily available modules/components in India.

IMPORTANT:
I am considering TP4056-based charging/protection boards, but evaluate whether that is appropriate for this ESP32/LiPo architecture.

I need to know:
1. Exact power architecture from LiPo → ESP32.
2. Whether the ESP32 can be powered directly from the LiPo.
3. Whether a 3.3 V regulator is required.
4. Whether the ESP32 development board's 5V/VIN input is appropriate.
5. Whether a boost/buck/boost-buck regulator is necessary.
6. How to safely charge the LiPo.
7. How to protect against overcharge, over-discharge and short circuit.
8. Recommended charging current for a 500 mAh cell.
9. Whether charging should be possible while the node is switched off.
10. Recommended connector between battery and PCB.
11. Recommended ON/OFF switch location.

BATTERY MONITORING
I want the ESP32 to measure LiPo voltage.

Design the voltage measurement circuit, including:
- resistor divider values
- ADC pin recommendation for ESP32-WROOM-32
- whether ADC1 should be used instead of ADC2 because Wi-Fi is active
- filtering capacitor if necessary
- maximum safe ADC voltage
- calibration considerations.

RGB LED
I have 5 mm, 4-pin RGB LEDs.

Preferred type:
- common cathode
- through-hole
- diffused

Common anode is also acceptable if necessary.

The RGB LED should indicate battery state:

GREEN = battery healthy
YELLOW = battery getting low
RED = battery low
FLASHING RED = critically low

Recommend practical voltage thresholds for a 1S LiPo under ESP32 load.

Do NOT pretend LiPo voltage maps linearly to battery percentage. I primarily need a reliable "OK / low / recharge" indication.

Design the LED circuit with appropriate current-limiting resistors.

I want to understand:
- how many GPIOs are needed
- resistor values
- common cathode vs common anode wiring
- whether PWM is necessary
- whether yellow can be created by red+green simultaneously.

LED CURRENT
Keep LED current modest because this is a battery-powered node.

Recommend sensible LED currents rather than simply using 20 mA per colour.

PERFBOARD
The final prototype will be soldered on perfboard.

Provide:
1. Schematic-level wiring description
2. Exact component list/BOM for ONE node
3. Suggested values
4. Wiring diagram in ASCII
5. Charging safety notes
6. ESP32 firmware logic/pseudocode for battery measurement and RGB status
7. Recommended PCB/perfboard layout
8. Common mistakes to avoid.

Assume the builder is technically capable but is not an electronics specialist, so explain important decisions clearly.

Optimize for:
- safety
- reliability
- low cost
- easy sourcing in India
- repeatability across approximately 20 nodes.

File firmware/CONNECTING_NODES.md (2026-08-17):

# Connecting 3 ESP32s to the laptop

Goal: prove the network path works with real hardware, **before you solder
anything**. USB power only, no sensors, no battery.

```
ESP32 (USB power) --> 2.4 GHz Wi-Fi --> router --> laptop --> dashboard
```

If this doesn't work, no amount of good soldering will save it. Find out now.

---

## Before anything else: two blockers on this laptop

### 1. Your Wi-Fi is 5 GHz. The ESP32 cannot use it.

The laptop is on **`krishna-5G`, 802.11ac, 5 GHz**. The ESP32's radio is
**2.4 GHz only** — this is a hardware limit, not a setting. It will never see
that network, no matter what you type.

**What to do:** find the 2.4 GHz SSID on the same router (often `krishna`,
`krishna-2G`, or similar — check the router admin page or the label on the
back). Put *that* SSID in the firmware.

The laptop can stay on 5 GHz. Both bands on one router are normally bridged to
the same subnet, so a node on 2.4 GHz can still reach a laptop on 5 GHz. If it
can't, check the router doesn't have **AP isolation** or **client isolation**
enabled — that blocks device-to-device traffic and would stop this dead.

> For the event itself, the TP-Link Archer AX53 should have 2.4 GHz broadcast
> as its own distinct SSID, *not* merged with 5 GHz under one name. Band
> steering with a single SSID confuses ESP32s badly.

### 2. Windows has this network as "Public", and there's no firewall rule

On a Public network Windows blocks inbound connections, so the ESP32s' HTTP
POSTs never reach the server. Two commands in an **Administrator PowerShell**:

```powershell
Set-NetConnectionProfile -InterfaceAlias "WiFi 4" -NetworkCategory Private
```

```powershell
New-NetFirewallRule -DisplayName "TASL Dashboard (TCP 8000)" -Direction Inbound -Action Allow -Protocol TCP -LocalPort 8000 -Profile Private
```

To undo later: `Remove-NetFirewallRule -DisplayName "TASL Dashboard (TCP 8000)"`

Check both at any time with:

```powershell
powershell -ExecutionPolicy Bypass -File tools\preflight.ps1
```

---

## Step 1 — Install ESP32 support in Arduino IDE

Arduino IDE is installed but has never been opened, and ESP32 support isn't
there yet.

1. Open **Arduino IDE**.
2. **File → Preferences**. In *Additional boards manager URLs*, paste:
   ```
   https://espressif.github.io/arduino-esp32/package_esp32_index.json
   ```
3. **Tools → Board → Boards Manager**, search `esp32`, install
   **"esp32" by Espressif Systems**. It's a few hundred MB — give it time.
4. **Tools → Board → esp32 → "DOIT ESP32 DEVKIT V1"**.

No libraries to install. `WiFi.h` and `HTTPClient.h` come with the core.

## Step 2 — USB driver

Plug in a board and look at **Tools → Port**. If no new COM port appears, the
USB-serial chip needs a driver. Look at the small chip near the USB socket:

| Chip | Driver |
|---|---|
| CP2102 | Silicon Labs CP210x VCP driver |
| CH340 / CH9102 | WCH CH341SER driver |

Use a **data** USB cable. Charge-only cables are extremely common and give
exactly this symptom — power LED on, no COM port.

## Step 3 — Edit the firmware

Open `firmware/tasl_node_conn_test/tasl_node_conn_test.ino` and edit the four
marked lines near the top:

```cpp
#define NODE_ID  "NODE01"                       // NODE01 / NODE02 / NODE03
const char* WIFI_SSID = "your 2.4GHz SSID";
const char* WIFI_PASS = "your wifi password";
const char* SERVER_IP = "192.168.1.37";         // this laptop
```

`192.168.1.37` is this laptop's current address. Confirm it with `ipconfig` or
the preflight script before each session — **if it changes, every node goes
silent.** Set a DHCP reservation on the router so it can't move.

## Step 4 — Flash each board

Flash all three, **changing `NODE_ID` each time**:

| Board | `NODE_ID` |
|---|---|
| 1st | `NODE01` |
| 2nd | `NODE02` |
| 3rd | `NODE03` |

Press **Upload** (arrow icon). If it stalls at `Connecting......`, hold the
**BOOT** button until upload starts, then release. Some DevKit V1 boards need
this; some auto-reset fine.

## Step 5 — Watch it connect

Open **Tools → Serial Monitor**, set baud to **115200**. You should see:

```
=====================================
 TASL node - connection test firmware
  node id : NODE01
  firmware: conn-test-1.0.0
=====================================
[wifi] connecting to "krishna" ...
[wifi] CONNECTED
       node id : NODE01
       my IP   : 192.168.1.52
       gateway : 192.168.1.1
       signal  : -47 dBm
       server  : http://192.168.1.37:8000
[evt] BOOT sent
```

## Step 6 — Run the dashboard

```bash
python run_server.py
```

Open <http://localhost:8000>. Within a few seconds each flashed board should
turn **ONLINE**.

**Press the BOOT button** on any board — a fake ball event appears on that
node's card and in the event log. That's the full path proven: node → Wi-Fi →
laptop → browser.

Batteries will show as **grey/empty** — correct, since nothing is wired to
measure them yet. That's Step 2.

---

## Reading the onboard LED

| LED (blue, GPIO2) | Meaning |
|---|---|
| Fast blinking | Connecting to Wi-Fi |
| Short flash every 2 s | Connected, heartbeat sent |
| Three rapid flashes | Send failed — message queued for retry |

---

## If it doesn't work

Work down this list in order. Each step splits the problem in half.

**Serial Monitor shows nothing / garbage**
Wrong baud rate — set 115200. Garbage at the right baud means a bad cable.

**`[wifi] FAILED to connect`**
- SSID is 5 GHz — the most likely cause here.
- SSID is case sensitive. `Krishna` ≠ `krishna`.
- Password wrong.
- SSID has emoji or unusual characters — ESP32 handles these poorly.

**Connects to Wi-Fi, but `[net] no response (-1)`**
The node is on the network but can't reach the server.
1. Is `python run_server.py` actually running?
2. Did you run both firewall commands above?
3. Does the node's IP start with `192.168.1.`? If it's `192.168.4.x` or
   similar, it joined a guest network or a different router.
4. Router **AP isolation** — check it's off.
5. From another phone on the same 2.4 GHz Wi-Fi, open
   `http://192.168.1.37:8000`. If the phone can't reach it either, the problem
   is the laptop/firewall, not the ESP32.

**`[net] REJECTED: server does not know node_id "NODEXX"`**
`NODE_ID` in the firmware doesn't match `config/nodes.json`. Case sensitive.

**Node appears then goes OFFLINE repeatedly**
Weak signal. Check the `dBm` on its card — below −78 expect trouble. Move the
node or the router.

**Two boards both show as NODE01**
You forgot to change `NODE_ID` before flashing the second board. The dashboard
will show one node behaving very strangely.

---

## When this works

You've proven: Wi-Fi credentials, laptop IP, firewall, protocol, event
delivery and the offline queue — all with real hardware. Everything after this
is soldering, and if a node then misbehaves you know the network isn't why.

Next: **Step 2**, the battery circuit — TP4056 charging, the divider into an
ADC1 pin, RGB LED thresholds, and the JST-XH net table.

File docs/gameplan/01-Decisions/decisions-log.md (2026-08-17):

# Decisions Log

## Economy

**Coins are uniform.** Every team gets 2,000 Kasu in identical denominations (500×2, 100×3, 50×8, 20×10, 10×10). All asymmetry lives in the materials. Uniform cash means no team can attribute its outcome to its endowment, which keeps the debrief clean.

**Buyback stays 100% fresh / 50% modified**, for speed at the counter during a rush. Buyback is valued against the **base price**, never the live price — otherwise a team that stockpiles before the war announcement can sell back at the higher price for risk-free profit.

**All prices are multiples of 20**, so the 50% buyback always lands on an amount payable with 10/20/50/100/500 coins.

**MOQ is 1** on every depot line.

## Materials

**Depot stock = 1.5 × basekit quantity** on every line. 100% for trading, 50% as reserve. Designed scarcity comes from unequal kits and from price — never from an empty shelf. A stockout makes the price mechanism meaningless and forces the crew to improvise rulings.

**Kits supply about 85% of each team's structural frame**, and structural prices were halved. At the earlier 30% level, closing the structural gap cost the room 32,360 Kasu against 20,000 in circulation — teams would have run out of money before their frames were standing. Frames are the boring part and should not eat the budget.

**Balls are not sold at the depot.** Ball size is a God Mode lever.

**Removed:** telescopic slip coupler, inspection bend with access door, hose clamps.

**Added to kits:** permanent marker (1 each), rubber mallet (1 each), A3 sheets (2 each), 32mm tee, 32mm end cap, 76mm split bend, 2 narrow buckets for Team 10.

**Added to depot only:** funnel, priced at 200 so building a cardboard catcher stays the cheaper option — Teams 4 and 5 still have to solve their own catch.

## Sizing

**Standardised to mm.** All inch notation dropped; mm is what's printed on the pipe.

- Structural supports — **25mm OD, 15kg**
- Closed pathway — **32mm OD, 10kg** (ID ≈ 28mm)
- Open pathway — **76mm split lengthways, SWR Type B**

Three-way and four-way corners are **PVC furniture fittings**, a different product line from plumbing stock and sourced separately. A plumbing "cross" is flat and cannot build a box frame.

## Room information design

**No inventory board and no want/have board.** Both need maintenance nobody has time for, and both go stale within the hour. Replaced by two things that maintain themselves:

- **Large table numbers**, readable across the hall
- **A spares tray on every table** — teams put what they don't need where others can see it. It cannot go stale, because it *is* the inventory.

## Depot operation

**Nandha and Yashwanth are paired on the depot** — Yashwanth on the transaction counter, Nandha on a separate cutting bay with power tools. Navaneeth works both queues.

**Participants never touch power tools.** No exceptions.

**Cutting bay: free, max 5 cuts per team per visit**, then back of the queue. Teams have hand tools, so the bay is a speed upgrade rather than a necessity — the queue is the price. Without a cap, one person with a saw becomes the bottleneck for the whole room.

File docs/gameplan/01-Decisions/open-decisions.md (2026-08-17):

# Open Decisions

Ordered by what blocks the most downstream work.

## 1. Path A ball ceiling — blocks kit packing

Teams build to whatever gauge they hold. Path A currently carries a 12mm ball, and Yoga can upgrade a struggling path mid-game. But if those four teams (2, 4, 6, 8) build 12mm catchers and apertures, a 20mm or 25mm ball physically will not pass and the lever cannot fire.

**Decide the ceiling, then put a gauge of that size in those four kits.** Make it a ball on a dowel handle, not a loose ball — a loose one gets rolled through the run "just to see", and if the gauge is also the upgrade ball, teams will simply start using it early.

## 2. Confirm 32mm passes a 25mm ball — blocks the whole materials set

32mm at 10kg gives ID ≈ 28mm, so a 25mm ball has 1.5mm clearance per side.

**Test:** roll a 25mm ball through a **32mm long-radius bend** and through a **freshly scissor-cut pipe end**, both under gravity at a shallow tilt.

- The bend, because a rigid ball cuts across a curve and presses into the outer wall. It needs a bend radius of at least ~50mm.
- The cut end, because a PVC scissor cutter pinches the bore inward by 1–2mm as it cuts.

If either hangs, the closed pathway moves to 40mm and every quantity shifts with it.

Note this makes **short 90° elbows impassable for the 25mm ball but fine for the 12mm ball** — worth knowing, since it becomes a real trade between paths.

## 3. Team 5 challenge wording

"Make an open air jump **within** 0.75 feet" — is that a minimum gap or a maximum? Currently written as a minimum, matching Team 4's, so it reads as an easier version of the same challenge.

## 4. Bucket diameter

Team 10 gets 2 and the depot holds 3, so the target width is fixed by what you buy. A narrow cup makes the dead drop the hardest module in the room; a wide bucket makes it nearly automatic.

## 5. Award categories

Fourteen candidates in `05-Awards/`. Pick ten — one per team.

## 6. Budget items not in the ₹1.9L materials line

- **Depot inventory**, roughly ₹25,000–30,000
- **Frame ballast** — sandbags or weights. A 2m PVC tower will rock, and Team 2's climb needs a rigid base. Not in any list yet.

## 7. Photography

All six crew have jobs during the run, and the news-flash videos still need running. Either a seventh person for capture, or accept uneven phone footage.

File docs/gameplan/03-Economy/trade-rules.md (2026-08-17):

# Trade Rules

1. The depot sells at the **live** price on the board. The board is the truth.
2. The depot buys back at the **base** price, whatever the board says at the time.
3. Fresh and unused → 100% of base. Cut or modified but still usable → 50% of base. Unusable → rejected, no value.
4. The depot transacts in board units only.
5. **One nominated Trader per team.** Only Traders approach the counter — sixty people at one counter stops the game.
6. Team-to-team trade is unrestricted: material, coins, labour, tools on loan, favours.
7. Safety gear is **not tradeable**. It stays with the team.
8. **Cutting bay:** free, maximum 5 cuts per team per visit, then back of the queue. Participants never touch the power tools.

## Why buyback is against base price

With buyback at the live price, a team that stockpiles before the war announcement sells back afterwards at 20% more — risk-free profit that drains the coin stash and inflates the money supply at exactly the moment you were trying to squeeze it.

Print two columns on the board: **live buy price** (changes) and **base value** (fixed). Depot staff read a fixed printed number and halve it. Same mental load, no arbitrage.

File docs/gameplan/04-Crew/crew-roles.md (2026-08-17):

# Crew

| Person | Post | Owns |
|---|---|---|
| **Sivagami** | Front of House | Mic, opening brief, every announcement, room energy, runs the debrief, calls God Mode |
| **Navaneeth** | Time Control | Clock, God Mode panel, live price updates, depot queue, material logistics |
| **Krishna** | Technical Handler | Sensor modules, GUI and trigger debugging, coordination |
| **Yoga** | Master of Challenges | Parameter troubleshooting, distances between teams, ball-size release decisions |
| **Nandha** | Depot — Cutting Bay | Power tools, cuts on behalf of teams, tool safety, first aid |
| **Yashwanth** | Depot — Counter | Coins, prices, buyback rulings, float |

Nandha and Yashwanth are paired deliberately — they coordinate well and the depot is two stations, not one.

## Krishna: technique yes, strategy no

You designed the game. You know the trap items, who holds what, and which path needs braking.

**Can say:** how to cut square, how to deburr, how to brace a flexing frame, which tool to use.

**Must not say:** which fittings suit a ball path · which team holds what they need · that one path needs slowing and the other speeding up · anything starting with "have you tried…"

When tempted, ask a question instead of giving an answer.

## Gaps

**Nobody is holding a camera.** All six have jobs during the run, and the news-flash videos still need running.

**Debrief material.** The reflection is only as good as what someone wrote down at 1:45. Whoever is on the floor should keep running notes — who traded with whom, who got stuck and how they got out, who spotted something first.

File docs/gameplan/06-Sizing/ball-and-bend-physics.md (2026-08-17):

# Ball and Bend — what decides whether the run works

## Clearance

| Ball | In 28mm ID | Occupancy |
|---|---|---|
| 12 mm | 8 mm gap | 43% |
| 25 mm | 1.5 mm gap | 89% |

Below about half the bore a ball ricochets rather than rolls — it wanders off the centreline and scrubs speed unpredictably. Above about two-thirds it's channelled and repeatable.

## Bend radius — the constraint that matters

A ball is rigid, a bend is curved. The ball can't hug the curve, so it cuts across and presses into the outer wall. The tighter the bend, the harder it presses.

**Minimum centreline bend radius ≈ r² / 2(a − r)** where r = ball radius, a = tube inner radius.

For a 25mm ball in 28mm ID: **R ≥ 52mm**.

| | Pushes ball outward | 1.5mm available | Result |
|---|---|---|---|
| 32mm short elbow (R ≈ 40mm) | ~2mm | not enough | **jams** |
| 32mm long-radius bend (R ≈ 95mm) | ~1mm | enough | passes |

The 12mm ball needs only R ≥ 5mm, so it passes everything including sharp corners.

**Consequence:** short 90° elbows are impassable for the 25mm ball and perfectly usable for the 12mm one. Path B teams holding short elbows physically cannot use them; Path A teams can. That's a real trade emerging from the physics, discoverable in about ninety seconds of testing.

## The other constriction — cut ends

A PVC scissor cutter works by pinching, and deforms the bore inward by 1–2mm at the cut. With 1.5mm clearance that alone can stop a 25mm ball. **Reaming after every cut is mandatory, not good practice.** It's also the strongest argument for the cutting bay producing square, undeformed cuts.

## Not a constriction — socket shoulders

At a solvent-weld joint the pipe seats into a socket bored to the pipe's **OD**, and the shoulder where that socket steps down to the waterway faces away from a ball travelling inside the pipe. Pipe ID ≈ 28mm, fitting waterway ≈ 28mm. The ball goes 28 → 28.

## Launcher energy

Team 2 must climb 1.5 ft **above** launch height, so the ball needs ≥ 3.0 m/s at the foot of the climb — call it 4–5 m/s at launch after losses. That needs a real elastic launcher, not a gravity ramp.

With a shared trigger, a lighter ball takes far more velocity from the same stored energy — roughly 3× for a 12mm against a 25mm — and climb height goes as v². That's why the small ball takes the climbing path.

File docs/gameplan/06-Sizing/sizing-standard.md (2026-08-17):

# Sizing Standard

All sizes are **pipe OD in mm** — what's printed on the pipe. **kg** denotes pressure class, which is wall thickness. Inch notation is not used anywhere.

| Use | Spec |
|---|---|
| Structural supports and frames | **25mm OD, 15kg** |
| Closed pathway (ball travels inside) | **32mm OD, 10kg** — ID ≈ 28mm |
| Open pathway | **76mm split lengthways, SWR Type B** |

## Why these

**25mm at 15kg** for structure — the thicker wall resists flexing, which matters because a springy frame absorbs the momentum Team 2 needs for the climb. It's also the size PVC furniture fittings are actually available in.

**32mm at 10kg** for pathway — ID ≈ 28mm passes a 25mm ball with 1.5mm clearance per side. Verified physically.

**76mm SWR Type B** for the open channel — Type A is thinner and a split length will sag and flatten. A split pipe loses nearly all its hoop stiffness.

## Sourcing notes

**Three-way and four-way corners are PVC furniture fittings**, a different product line from plumbing stock. A plumbing "cross" is flat — all four outlets in one plane — and cannot build a box frame. Mostly available in 20mm and 25mm only, and not stocked by ordinary plumbing counters.

**Long-radius 90° bends and Y junctions** are common in SWR and uncommon in 32mm pressure fittings. Confirm availability before finalising.

**76mm cannot be cut with kit tools.** A PVC scissor cutter tops out around 42mm. All 76mm is pre-split and pre-cut before the day.

## Frame geometry

| Structure | 25mm pipe | Three-way | Four-way |
|---|---|---|---|
| 1m cube, 1 level | 12 m | 8 | 0 |
| 1m cube, 2 levels | 20 m | 8 | 4 |

Two stacked cubes: 12 horizontal edges plus 8 vertical. Bottom and top corners are three-way; the four mid-height corners take a vertical from above and below, so they're four-way.

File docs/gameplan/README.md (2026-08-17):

# GamePlan — TASL Marble Run

Working documents for the marble run day. Ten teams of six, four hours, one shared run.

## Contents

| Folder | What's in it |
|---|---|
| `01-Decisions/` | Decisions taken, and what's still open |
| `02-BOM/` | Basekit contents, totals, depot materials, procurement list |
| `03-Economy/` | Coins, trade rules, God Mode levers |
| `04-Crew/` | Who does what, phased across the day |
| `05-Awards/` | Award categories for the wrap-up |
| `06-Sizing/` | Pipe standardisation and the ball/bend physics behind it |
| `07-Team-Guides/` | Participant guide books |
| `data/` | Machine-readable JSON for parallel development — prices, events, coins, teams |
| `scripts/` | `push-gameplan.sh` to publish this folder; guide book generator |

## Stock sizing

The venue is remote and nothing can be sourced on the day. Depot stock is the greater of 1.5× basekit quantity, or enough to bring total availability to **twice estimated consumption**. Every line sits at or above 2×.

## The design in one paragraph

Two balls launch together from Team 1, travel two independent paths through the room, and must land in their buckets at the same time. Each team owns one section and must hand off to the next. Basekits are deliberately unequal so no team can finish alone. Coins are uniform at 2,000 Kasu per team, so any difference in outcome comes from material position and trading, not endowment. Prices at the depot rise with scripted news events, which squeezes teams who leave their buying late.

## Rules the design depends on

- A shortage may be inconvenient, never fatal. Anything that can deadlock the run is issued in kits and stocked deep.
- Designed scarcity lives in the kits and in price. The depot never runs out — depot stock is 1.5× basekit on every line.
- Buyback is always against the base price, never the live one. Without this, teams can arbitrage the price shocks.
- Balls are not purchasable. Ball size stays a facilitator lever.

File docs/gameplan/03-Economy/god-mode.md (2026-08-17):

# God Mode

| Lever | Effect | Cap / rule |
|---|---|---|
| **War** | Prices +20% | Scheduled, 1:30 |
| **Tariff** | Prices +30% more | Scheduled, 2:00 |
| **Ball upgrade** | Small ball → larger | **Per path, not per team.** Announce as a client spec change, not a rescue. **Locked after 2:00** |
| **Targeted bailout** | 600–1,000 Kasu to one stuck team | Do not broadcast. Maximum twice |
| **Free money** | Broadcast cash | Maximum 2,000 total (10% of circulation). Avoid — it undoes the price squeeze |
| **Demonetisation** | 500-coin withdrawn, exchange at depot within 10 minutes at 60% | Use once, before 2:00 |

## Ball upgrade — the rules that make it work

**Per path, not per team.** Ball size is a system-wide parameter for everything downstream of the launcher. The two paths are independent until Team 10, so per-path is the correct granularity.

**Locked at 2:00.** From 2:00 to 3:00 Teams 8 and 9 are calibrating arrival times. A bigger ball has a different loss profile, so handing one over at 2:40 voids every measurement they have taken.

**Frame it as a spec change, not a bailout.** Announcing *"the client has revised the payload spec"* removes the stigma, avoids teams learning that visible struggle produces free help, and turns a mercy into the most realistic lesson of the day.

**It helps everyone except Team 8**, whose job is to brake the fast path. Expect their demand for flexi hose and foam to spike the moment you announce.

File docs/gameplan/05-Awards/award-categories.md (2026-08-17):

# Award Categories

**Not competitive.** The theme is subsystems working together for the organisation's success, so awards recognise qualities rather than rank teams.

## Structure of the wrap-up

Open with the **collective result** before any award — both balls, and the gap between them in seconds. Not a prize, just the number. It frames everything after it as recognition rather than ranking, and makes the point that the room succeeded or didn't as one system.

Then **one award per team**, chosen from the pool below. Ten teams of six senior people is small enough that a team receiving nothing will notice, and that undercuts the theme.

Fourteen candidates so the crew can match honestly rather than force a fit.

## The pool

| Award | Recognises | How to spot it |
|---|---|---|
| **Good Neighbour** | The handover, judged by the teams either side | Nominated by adjacent teams only — the one award decided by peers |
| **The Long View** | Changed their own design so someone else's job became possible | Rebuilt something that already worked, for another team's benefit |
| **Frugal Engineer** | Most result per Kasu | Working module, money still in the tin |
| **Best Trade** | One negotiation that left both sides better off | Trade log; ask both parties separately |
| **Market Maker** | Kept material moving whether or not it profited them | Named by several unrelated teams as someone they dealt with |
| **Elegant Solution** | The simplest mechanism that did the job | Fewest parts, least fuss, obviously right once you see it |
| **Improvisation** | Solved it with material never intended for that use | Cardboard doing a job PVC was meant to do |
| **Measure Twice** | Numbers right the first time | Measured height matched claimed height |
| **The Clean Build** | Assembly quality | Square cuts, no wobble, nothing held together by hope |
| **Weathered the Storm** | Best response to the war and tariff | Bought early, or adapted rather than complained |
| **Called It Early** | Anticipated something before it happened | Stockpiled or repositioned ahead of a shift |
| **The Debug** | Found and fixed a fault fast — theirs or someone else's | Usually the team that walked over to help |
| **Held the Line** | Recovered from a setback without derailing the room | Something collapsed and they rebuilt without drama |
| **Best Looking Run** | The module people wanted to photograph | Self-evident |

## Protect Good Neighbour

It's the only award teams decide about each other, and it's closest to the actual lesson — your subsystem is judged by the people it hands to, not by how good it looks on its own. Consider giving it twice.

## This depends on notes

These have to be decided from what someone actually noticed at 1:45, not invented during the wrap-up. Whoever is on the floor keeps running notes on their teams throughout.

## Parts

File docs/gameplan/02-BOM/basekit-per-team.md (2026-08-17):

# Basekit — Materials per Team

All sizes are pipe OD in mm. Common to every box: tape measure, PVC cutter, junior hacksaw, paper knife, 2 pairs gloves, 2 safety glasses, guide book.

Coins in every box: 500 × 2, 100 × 3, 50 × 8, 20 × 10, 10 × 10 = **2,000 Kasu, 33 coins**.

## Team 1 — Launch

| Item | Qty |
|---|---|
| 25mm pipe, 1m | 20 |
| 25mm three-way corner (PVC furniture fittings) | 8 |
| 25mm four-way corner (PVC furniture fittings) | 4 |
| 25mm tee | 8 |
| 25mm elbow 90° | 5 |
| 25mm coupler | 3 |
| 25mm end cap | 4 |
| 25mm saddle clamp | 6 |
| 32mm pipe, 1m | 2 |
| 32mm elbow 90° (short radius) | 4 |
| 32mm tee | 2 |
| 32mm end cap | 1 |
| 32mm coupler | 2 |
| Cardboard blank (sheet) | 2 |
| Zip ties (pack of 10) | 1 |
| Duct tape | 1 |
| Elastic cord set | 2 |
| Dowel pack | 2 |
| A3 sheets | 2 |
| Permanent pen tip marker | 1 |
| Rubber mallet | 1 |
| Ball 12 mm | 1 |
| Ball 25 mm | 1 |

## Team 2 — Raise Elevation

| Item | Qty |
|---|---|
| 25mm pipe, 1m | 18 |
| 25mm three-way corner (PVC furniture fittings) | 6 |
| 25mm four-way corner (PVC furniture fittings) | 3 |
| 25mm tee | 4 |
| 25mm elbow 90° | 2 |
| 25mm coupler | 3 |
| 25mm end cap | 3 |
| 25mm saddle clamp | 4 |
| 32mm pipe, 1m | 4 |
| 32mm elbow 90° (short radius) | 4 |
| 32mm tee | 1 |
| 32mm end cap | 1 |
| 32mm coupler | 2 |
| Cardboard blank (sheet) | 4 |
| Zip ties (pack of 10) | 4 |
| Fevicol | 1 |
| Scissors | 1 |
| Duct tape | 1 |
| A3 sheets | 2 |
| Permanent pen tip marker | 1 |
| Rubber mallet | 1 |
| Ball 12 mm | 1 |

## Team 3 — Drop Elevation

| Item | Qty |
|---|---|
| 25mm pipe, 1m | 24 |
| 25mm three-way corner (PVC furniture fittings) | 12 |
| 25mm four-way corner (PVC furniture fittings) | 4 |
| 25mm tee | 8 |
| 25mm elbow 90° | 6 |
| 25mm coupler | 8 |
| 25mm end cap | 8 |
| 25mm saddle clamp | 5 |
| 32mm pipe, 1m | 4 |
| 32mm elbow 90° (short radius) | 2 |
| 32mm bend 45° | 3 |
| 32mm tee | 1 |
| 32mm end cap | 1 |
| 76mm split channel, 1m (SWR Type B) | 3 |
| 76mm split bend 90° (SWR Type B) | 2 |
| Zip ties (pack of 10) | 1 |
| A3 sheets | 2 |
| Permanent pen tip marker | 1 |
| Rubber mallet | 1 |
| Ball 25 mm | 1 |

## Team 4 — Free Jump — Long

| Item | Qty |
|---|---|
| 25mm pipe, 1m | 14 |
| 25mm three-way corner (PVC furniture fittings) | 6 |
| 25mm tee | 5 |
| 25mm elbow 90° | 3 |
| 25mm coupler | 3 |
| 25mm end cap | 3 |
| 25mm saddle clamp | 5 |
| 32mm pipe, 1m | 3 |
| 32mm elbow 90° (short radius) | 2 |
| 32mm tee | 1 |
| 32mm end cap | 1 |
| 76mm split channel, 1m (SWR Type B) | 1 |
| 76mm split bend 90° (SWR Type B) | 1 |
| Cardboard blank (sheet) | 2 |
| Zip ties (pack of 10) | 2 |
| Dowel pack | 1 |
| A3 sheets | 2 |
| Permanent pen tip marker | 1 |
| Rubber mallet | 1 |
| Ball 12 mm | 1 |

## Team 5 — Free Jump — Short

| Item | Qty |
|---|---|
| 25mm pipe, 1m | 14 |
| 25mm three-way corner (PVC furniture fittings) | 6 |
| 25mm tee | 5 |
| 25mm elbow 90° | 3 |
| 25mm coupler | 3 |
| 25mm end cap | 3 |
| 25mm saddle clamp | 4 |
| 32mm pipe, 1m | 2 |
| 32mm bend 90° (long radius) | 2 |
| 32mm Y junction | 2 |
| 32mm end cap | 1 |
| 76mm split channel, 1m (SWR Type B) | 1 |
| Cardboard blank (sheet) | 8 |
| Zip ties (pack of 10) | 4 |
| Fevicol | 3 |
| Scissors | 3 |
| Duct tape | 3 |
| A3 sheets | 2 |
| Permanent pen tip marker | 1 |
| Rubber mallet | 1 |
| Ball 25 mm | 1 |

## Team 6 — Open Ended

| Item | Qty |
|---|---|
| 25mm pipe, 1m | 6 |
| 25mm three-way corner (PVC furniture fittings) | 2 |
| 25mm tee | 2 |
| 25mm elbow 90° | 1 |
| 25mm coupler | 1 |
| 25mm end cap | 1 |
| 25mm saddle clamp | 2 |
| 32mm pipe, 1m | 1 |
| 32mm elbow 90° (short radius) | 1 |
| 32mm tee | 1 |
| Cardboard blank (sheet) | 1 |
| Zip ties (pack of 10) | 1 |
| A3 sheets | 2 |
| Permanent pen tip marker | 1 |
| Rubber mallet | 1 |
| Ball 12 mm | 1 |

## Team 7 — Open Ended

| Item | Qty |
|---|---|
| 25mm pipe, 1m | 8 |
| 25mm three-way corner (PVC furniture fittings) | 10 |
| 25mm four-way corner (PVC furniture fittings) | 3 |
| 25mm tee | 4 |
| 25mm elbow 90° | 4 |
| 25mm coupler | 6 |
| 25mm end cap | 2 |
| 25mm saddle clamp | 14 |
| 32mm bend 45° | 2 |
| 32mm tee | 2 |
| 32mm end cap | 2 |
| 32mm coupler | 6 |
| 32mm × 25mm reducer bush | 4 |
| Split foam insulation, 1m | 2 |
| Zip ties (pack of 10) | 6 |
| A3 sheets | 2 |
| Permanent pen tip marker | 1 |
| Rubber mallet | 1 |
| Ball 25 mm | 1 |

## Team 8 — Time Keeper

| Item | Qty |
|---|---|
| 25mm pipe, 1m | 16 |
| 25mm three-way corner (PVC furniture fittings) | 6 |
| 25mm tee | 6 |
| 25mm elbow 90° | 4 |
| 25mm coupler | 3 |
| 25mm end cap | 4 |
| 25mm saddle clamp | 6 |
| 32mm pipe, 1m | 3 |
| 32mm bend 90° (long radius) | 1 |
| 32mm elbow 90° (short radius) | 2 |
| 32mm tee | 1 |
| 32mm end cap | 1 |
| 76mm split channel, 1m (SWR Type B) | 2 |
| 76mm split bend 90° (SWR Type B) | 1 |
| Cardboard blank (sheet) | 3 |
| Zip ties (pack of 10) | 3 |
| Sensor module | 1 |
| A3 sheets | 2 |
| Permanent pen tip marker | 1 |
| Rubber mallet | 1 |
| Ball 12 mm | 1 |

## Team 9 — Time Keeper

| Item | Qty |
|---|---|
| 25mm pipe, 1m | 14 |
| 25mm three-way corner (PVC furniture fittings) | 5 |
| 25mm tee | 5 |
| 25mm elbow 90° | 3 |
| 25mm coupler | 2 |
| 25mm end cap | 3 |
| 25mm saddle clamp | 5 |
| 32mm pipe, 1m | 3 |
| 32mm elbow 90° (short radius) | 3 |
| 76mm split channel, 1m (SWR Type B) | 1 |
| Flexible borewell hose, 1m | 5 |
| Split foam insulation, 1m | 4 |
| Zip ties (pack of 10) | 2 |
| Sensor module | 1 |
| A3 sheets | 2 |
| Permanent pen tip marker | 1 |
| Rubber mallet | 1 |
| Ball 25 mm | 1 |

## Team 10 — End Capture — Dead Drop

| Item | Qty |
|---|---|
| 25mm pipe, 1m | 20 |
| 25mm three-way corner (PVC furniture fittings) | 7 |
| 25mm four-way corner (PVC furniture fittings) | 3 |
| 25mm tee | 4 |
| 25mm elbow 90° | 3 |
| 25mm coupler | 2 |
| 25mm end cap | 3 |
| 25mm saddle clamp | 9 |
| 32mm pipe, 1m | 8 |
| 32mm bend 90° (long radius) | 1 |
| 32mm elbow 90° (short radius) | 2 |
| 32mm tee | 1 |
| 32mm end cap | 2 |
| 76mm split channel, 1m (SWR Type B) | 2 |
| 76mm split bend 90° (SWR Type B) | 2 |
| Cardboard blank (sheet) | 3 |
| Zip ties (pack of 10) | 2 |
| Fevicol | 1 |
| Duct tape | 1 |
| Narrow bucket / paper cup | 2 |
| A3 sheets | 2 |
| Permanent pen tip marker | 1 |
| Rubber mallet | 1 |
| Ball 12 mm | 1 |
| Ball 25 mm | 1 |

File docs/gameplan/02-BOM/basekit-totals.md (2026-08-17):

# Basekit — Total Quantities (10 teams)

| Item | Total Qty | Depot Stock (1.5×) |
|---|---|---|
| 25mm pipe, 1m | 154 | 231 |
| 25mm three-way corner (PVC furniture fittings) | 68 | 102 |
| 25mm four-way corner (PVC furniture fittings) | 17 | 26 |
| 25mm tee | 51 | 77 |
| 25mm elbow 90° | 34 | 51 |
| 25mm coupler | 34 | 51 |
| 25mm end cap | 34 | 51 |
| 25mm saddle clamp | 60 | 90 |
| 32mm pipe, 1m | 30 | 45 |
| 32mm bend 90° (long radius) | 4 | 32 |
| 32mm elbow 90° (short radius) | 20 | 30 |
| 32mm bend 45° | 5 | 25 |
| 32mm Y junction | 2 | 4 |
| 32mm tee | 10 | 15 |
| 32mm end cap | 10 | 15 |
| 32mm coupler | 10 | 30 |
| 32mm × 25mm reducer bush | 4 | 12 |
| 76mm split channel, 1m (SWR Type B) | 10 | 15 |
| 76mm split bend 90° (SWR Type B) | 6 | 9 |
| Flexible borewell hose, 1m | 5 | 11 |
| Split foam insulation, 1m | 6 | 10 |
| Cardboard blank (sheet) | 23 | 67 |
| Zip ties (pack of 10) | 26 | 39 |
| Fevicol | 5 | 15 |
| Scissors | 4 | 16 |
| Duct tape | 6 | 34 |
| Elastic cord set | 2 | 6 |
| Dowel pack | 3 | 9 |
| Narrow bucket / paper cup | 2 | 3 |
| Sensor module | 2 | 3 |
| A3 sheets | 20 | 30 |
| Permanent pen tip marker | 10 | 15 |
| Rubber mallet | 10 | 15 |
| Ball 12 mm | 6 | not sold |
| Ball 25 mm | 6 | not sold |
| Funnel | 0 (depot only) | 8 |
| **Total pieces** | **699** | |

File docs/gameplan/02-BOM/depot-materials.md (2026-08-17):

# Materials (Depot)

MOQ 1 on every line. All prices are multiples of 20 so the 50% buyback is always payable in coins.

Depot stock = 1.5 × basekit quantity — 100% for trading, 50% as reserve so nothing runs out.

Structural 25mm/15kg · Pathway 32mm/10kg · Open split channel 76mm SWR Type B.

## STRUCTURAL — 25mm OD, 15kg (supports and frames)

| Item | MOQ | Stock Qty | Initial Price | Buyback 50% |
|---|---|---|---|---|
| 25mm pipe, 1m | 1 | 231 | 60 | 30 |
| 25mm three-way corner (PVC furniture fittings) | 1 | 102 | 60 | 30 |
| 25mm four-way corner (PVC furniture fittings) | 1 | 26 | 80 | 40 |
| 25mm tee | 1 | 77 | 40 | 20 |
| 25mm elbow 90° | 1 | 51 | 40 | 20 |
| 25mm coupler | 1 | 51 | 20 | 10 |
| 25mm end cap | 1 | 51 | 20 | 10 |
| 25mm saddle clamp | 1 | 90 | 40 | 20 |

## PATHWAY CLOSED — 32mm OD, 10kg (ID ≈ 28mm)

| Item | MOQ | Stock Qty | Initial Price | Buyback 50% |
|---|---|---|---|---|
| 32mm pipe, 1m | 1 | 45 | 200 | 100 |
| 32mm coupler | 1 | 30 | 60 | 30 |
| 32mm elbow 90° (short radius) | 1 | 30 | 100 | 50 |
| 32mm bend 90° (long radius) | 1 | 32 | 300 | 150 |
| 32mm bend 45° | 1 | 25 | 180 | 90 |
| 32mm tee | 1 | 15 | 140 | 70 |
| 32mm Y junction | 1 | 4 | 220 | 110 |
| 32mm end cap | 1 | 15 | 40 | 20 |
| 32mm × 25mm reducer bush | 1 | 12 | 120 | 60 |

## PATHWAY OPEN — 76mm split, SWR Type B

| Item | MOQ | Stock Qty | Initial Price | Buyback 50% |
|---|---|---|---|---|
| 76mm split channel, 1m (SWR Type B) | 1 | 15 | 200 | 100 |
| 76mm split bend 90° (SWR Type B) | 1 | 9 | 240 | 120 |

## FLEX & FRICTION

| Item | MOQ | Stock Qty | Initial Price | Buyback 50% |
|---|---|---|---|---|
| Flexible borewell hose, 1m | 1 | 11 | 300 | 150 |
| Split foam insulation, 1m | 1 | 10 | 120 | 60 |

## CONSUMABLES

| Item | MOQ | Stock Qty | Initial Price | Buyback 50% |
|---|---|---|---|---|
| Cardboard blank (sheet) | 1 | 67 | 120 | 60 |
| Zip ties (pack of 10) | 1 | 39 | 80 | 40 |
| Fevicol | 1 | 15 | 200 | 100 |
| Scissors | 1 | 16 | 240 | 120 |
| Duct tape | 1 | 34 | 160 | 80 |
| Elastic cord set | 1 | 6 | 140 | 70 |
| Dowel pack | 1 | 9 | 100 | 50 |
| Permanent pen tip marker | 1 | 15 | 60 | 30 |
| Rubber mallet | 1 | 15 | 300 | 150 |
| Funnel | 1 | 8 | 200 | 100 |
| Narrow bucket / paper cup | 1 | 3 | 100 | 50 |
| A3 sheets | 1 | 30 | 20 | 10 |

## SPECIAL

| Item | MOQ | Stock Qty | Initial Price | Buyback 50% |
|---|---|---|---|---|
| Sensor module | 1 | 3 | 200 | 100 |

## Not sold at the depot

Balls (12mm and 25mm) are facilitator-controlled. Ball size is a God Mode lever, so teams cannot buy their way to a different one.

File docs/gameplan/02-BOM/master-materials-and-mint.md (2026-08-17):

# Master Materials & Mint

Everything in one place. If a number appears anywhere else in this repo, it comes from here.

## Materials

Structural 25mm/15kg · Pathway 32mm/10kg · Open split channel 76mm SWR Type B. Sizes are pipe OD in mm.

Depot stock = greater of 1.5x basekit, or enough for total availability to reach 2x estimated consumption. Venue is remote — nothing can be sourced on the day.

| Item | Basekit | Depot | **Total to buy** | MOQ | Price | Buyback 50% |
|---|---|---|---|---|---|---|
| 25mm pipe, 1m | 154 | 231 | **385** | 1 | 60 | 30 |
| 25mm three-way corner (PVC furniture fittings) | 68 | 102 | **170** | 1 | 60 | 30 |
| 25mm four-way corner (PVC furniture fittings) | 17 | 26 | **43** | 1 | 80 | 40 |
| 25mm tee | 51 | 77 | **128** | 1 | 40 | 20 |
| 25mm elbow 90° | 34 | 51 | **85** | 1 | 40 | 20 |
| 25mm coupler | 34 | 51 | **85** | 1 | 20 | 10 |
| 25mm end cap | 34 | 51 | **85** | 1 | 20 | 10 |
| 25mm saddle clamp | 60 | 90 | **150** | 1 | 40 | 20 |
| 32mm pipe, 1m | 30 | 45 | **75** | 1 | 200 | 100 |
| 32mm bend 90° (long radius) | 4 | 32 | **36** | 1 | 300 | 150 |
| 32mm elbow 90° (short radius) | 20 | 30 | **50** | 1 | 100 | 50 |
| 32mm bend 45° | 5 | 25 | **30** | 1 | 180 | 90 |
| 32mm Y junction | 2 | 4 | **6** | 1 | 220 | 110 |
| 32mm tee | 10 | 15 | **25** | 1 | 140 | 70 |
| 32mm end cap | 10 | 15 | **25** | 1 | 40 | 20 |
| 32mm coupler | 10 | 30 | **40** | 1 | 60 | 30 |
| 32mm × 25mm reducer bush | 4 | 12 | **16** | 1 | 120 | 60 |
| 76mm split channel, 1m (SWR Type B) | 10 | 15 | **25** | 1 | 200 | 100 |
| 76mm split bend 90° (SWR Type B) | 6 | 9 | **15** | 1 | 240 | 120 |
| Flexible borewell hose, 1m | 5 | 11 | **16** | 1 | 300 | 150 |
| Split foam insulation, 1m | 6 | 10 | **16** | 1 | 120 | 60 |
| Cardboard blank (sheet) | 23 | 67 | **90** | 1 | 120 | 60 |
| Zip ties (pack of 10) | 26 | 39 | **65** | 1 | 80 | 40 |
| Fevicol | 5 | 15 | **20** | 1 | 200 | 100 |
| Scissors | 4 | 16 | **20** | 1 | 240 | 120 |
| Duct tape | 6 | 34 | **40** | 1 | 160 | 80 |
| Elastic cord set | 2 | 6 | **8** | 1 | 140 | 70 |
| Dowel pack | 3 | 9 | **12** | 1 | 100 | 50 |
| Narrow bucket / paper cup | 2 | 3 | **5** | 1 | 100 | 50 |
| Sensor module | 2 | 3 | **5** | 1 | 200 | 100 |
| A3 sheets | 20 | 30 | **50** | 1 | 20 | 10 |
| Permanent pen tip marker | 10 | 15 | **25** | 1 | 60 | 30 |
| Rubber mallet | 10 | 15 | **25** | 1 | 300 | 150 |
| Ball 12 mm | 6 | — | **6** | — | not sold | — |
| Ball 25 mm | 6 | — | **6** | — | not sold | — |
| Funnel | 0 | 8 | **8** | 1 | 200 | 100 |
| **Total pieces** | **699** | **1192** | **1891** | | | |

## Facilitator spares — carried to site, never on the depot shelf

| Item | Qty | Why |
|---|---|---|
| Ball 12 mm | 20 | Small balls roll away. Losing them ends the event |
| Ball 25 mm | 20 | Same, and these double as clearance gauges |
| Clearance gauge (ball on dowel) | 10 | One per team, sized to the Path A ceiling |
| Sensor module | 5 | 2 in use, 3 spare |
| Buckets (final target) | 4 | 2 in use, 2 spare |
| Frame ballast (sandbag / weight) | 10 sets | A 2m PVC tower rocks |
| Solvent cement | 4 | Issue only on request |
| First aid kit | 2 | Power tools, hacksaws, 60 people |

## Mint — all coins

Currency: Kasu. Denominations 10 / 20 / 50 / 100 / 500.

### Basekit coins — identical in every box

| Coin | Per box | Value | × 10 teams |
|---|---|---|---|
| 500 | 2 | 1000 | 20 |
| 100 | 3 | 300 | 30 |
| 50 | 8 | 400 | 80 |
| 20 | 10 | 200 | 100 |
| 10 | 10 | 100 | 100 |
| **Total** | **33 coins** | **2,000** | **330 coins · 20,000 Kasu** |

### Depot floating stash — on the counter

| Coin | Qty | Value |
|---|---|---|
| 10 | 200 | 2000 |
| 20 | 150 | 3000 |
| 50 | 80 | 4000 |
| 100 | 10 | 1000 |
| 500 | 0 | 0 |
| **Total** | **440 coins** | **10,000** |

No 500s at the counter. The depot only ever receives them; its job is handing back small coins.

### Depot reserve stash — sealed, off the counter

| Coin | Qty | Value |
|---|---|---|
| 10 | 200 | 2000 |
| 20 | 150 | 3000 |
| 50 | 80 | 4000 |
| 100 | 20 | 2000 |
| 500 | 20 | 10000 |
| **Total** | **470 coins** | **21,000** |

### Total mint

| | Coins | Value |
|---|---|---|
| Basekit (10 teams) | 330 | 20,000 |
| Floating stash | 440 | 10,000 |
| Reserve stash | 470 | 21,000 |
| **Total** | **1,240** | **51,000 Kasu** |

Circulation in team hands is 20,000. Room-wide purchasing at base prices is roughly 16,000 — about 80%, which is where the war and tariff bite without stranding anyone.

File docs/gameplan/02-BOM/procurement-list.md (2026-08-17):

# Procurement List

Buy quantity = basekit total + depot stock.

| Item | Kits | Depot | **Buy** |
|---|---|---|---|
| 25mm pipe, 1m | 154 | 231 | **385** |
| 25mm three-way corner (PVC furniture fittings) | 68 | 102 | **170** |
| 25mm four-way corner (PVC furniture fittings) | 17 | 26 | **43** |
| 25mm tee | 51 | 77 | **128** |
| 25mm elbow 90° | 34 | 51 | **85** |
| 25mm coupler | 34 | 51 | **85** |
| 25mm end cap | 34 | 51 | **85** |
| 25mm saddle clamp | 60 | 90 | **150** |
| 32mm pipe, 1m | 30 | 45 | **75** |
| 32mm bend 90° (long radius) | 4 | 32 | **36** |
| 32mm elbow 90° (short radius) | 20 | 30 | **50** |
| 32mm bend 45° | 5 | 25 | **30** |
| 32mm Y junction | 2 | 4 | **6** |
| 32mm tee | 10 | 15 | **25** |
| 32mm end cap | 10 | 15 | **25** |
| 32mm coupler | 10 | 30 | **40** |
| 32mm × 25mm reducer bush | 4 | 12 | **16** |
| 76mm split channel, 1m (SWR Type B) | 10 | 15 | **25** |
| 76mm split bend 90° (SWR Type B) | 6 | 9 | **15** |
| Flexible borewell hose, 1m | 5 | 11 | **16** |
| Split foam insulation, 1m | 6 | 10 | **16** |
| Cardboard blank (sheet) | 23 | 67 | **90** |
| Zip ties (pack of 10) | 26 | 39 | **65** |
| Fevicol | 5 | 15 | **20** |
| Scissors | 4 | 16 | **20** |
| Duct tape | 6 | 34 | **40** |
| Elastic cord set | 2 | 6 | **8** |
| Dowel pack | 3 | 9 | **12** |
| Narrow bucket / paper cup | 2 | 3 | **5** |
| Sensor module | 2 | 3 | **5** |
| A3 sheets | 20 | 30 | **50** |
| Permanent pen tip marker | 10 | 15 | **25** |
| Rubber mallet | 10 | 15 | **25** |
| Ball 12 mm | 6 | — | **6** |
| Ball 25 mm | 6 | — | **6** |
| Funnel | 0 | 8 | **8** |
| **Total pieces** | **699** | **1192** | **1891** |

## Coins

| | Qty |
|---|---|
| Basekit coins (10 teams) | 330 |
| Depot floating stash | 440 |
| Depot reserve stash | 470 |
| **Total mint** | **1,240** |

## Facilitator equipment (not in kits or depot)

| Item | Qty | Note |
|---|---|---|
| Sensor modules | 2 + spares | Teams 8 and 9 |
| Balls 12mm | 6 + spares | Path A |
| Balls 25mm | 6 + spares | Path B, plus clearance gauges |
| Frame ballast | 10 sets | Sandbags or weights — not yet specced |
| Buckets (final target) | 2 + spares | Diameter sets Team 10's difficulty |

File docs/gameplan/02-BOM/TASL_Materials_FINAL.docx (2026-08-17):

# Summary of Changes

- Sizing standardised to mm throughout. Structural 25mm/15kg · Pathway 32mm/10kg · Open split channel 76mm SWR Type B. All inch notation removed.
- Basekit and depot item names now match exactly — every item in a kit can be bought, and nothing is sold that no kit contains.
- Materials (Depot) table populated. It was blank apart from the sensor module.
- Structural allocations increased: kits now supply about 85% of each team's frame, up from 30%. Structural prices halved to match.
- Depot stock set at 1.5× basekit quantity on every line — 100% for trading, 50% as reserve so nothing runs out.
- MOQ is 1 on every line. All prices are multiples of 20 so the 50% buyback is always payable in coins. Buyback column added.
- Hose clamps removed. Duplicated quantities corrected in Teams 1, 8 and 10.
- Added to kits: permanent marker (1 each), rubber mallet (1 each), A3 sheets (2 each), 32mm tee, 32mm end cap, 76mm split bend, 2 narrow buckets for Team 10.
- Added to depot only: funnel, priced so building a cardboard catcher stays the cheaper option.
- Price reductions: 76mm split channel 320→200, 76mm split bend 400→240, 32mm Y junction 320→220.
- Balls are not sold at the depot — ball size stays a facilitator decision.
- Three-way and four-way corners labelled as PVC furniture fittings; they come from a different supplier to the rest.

# Open Decisions

- Ball size ceiling for Path A. Teams build to whatever gauge they hold, so if Path A may be upgraded to 20mm or 25mm, those four kits need a gauge of that size.
- Confirm a 25mm ball passes a 32mm long-radius bend and a freshly cut pipe end. If it hangs, the closed pathway moves to 40mm.
- Team 5 challenge wording: is 0.75 ft a minimum gap or a maximum?
- Bucket diameter — it sets the difficulty of Team 10's dead drop.
- Award categories.
- Depot inventory is roughly ₹25,000–30,000 and is not in the ₹1.9L materials line.
- Frame ballast (sandbags or weights) is not yet in any list. A 2m PVC tower will rock.

# Basekit Materials & Challenges

Structural allocations increased so each team is issued most of its own frame. Sizes are pipe OD in mm.

Team | Basekit Materials
1 | 20 x 25mm pipe, 1m 8 x 25mm three-way corner (PVC furniture fittings) 4 x 25mm four-way corner (PVC furniture fittings) 8 x 25mm tee 5 x 25mm elbow 90° 3 x 25mm coupler 4 x 25mm end cap 6 x 25mm saddle clamp 2 x 32mm pipe, 1m 4 x 32mm elbow 90° (short radius) 2 x 32mm tee 1 x 32mm end cap 2 x 32mm coupler 2 x Cardboard blank (sheet) 1 x Zip ties (pack of 10) 1 x Duct tape 2 x Elastic cord set 2 x Dowel pack 2 x A3 sheets 1 x Permanent pen tip marker 1 x Rubber mallet 1 x Ball 12 mm 1 x Ball 25 mm
2 | 18 x 25mm pipe, 1m 6 x 25mm three-way corner (PVC furniture fittings) 3 x 25mm four-way corner (PVC furniture fittings) 4 x 25mm tee 2 x 25mm elbow 90° 3 x 25mm coupler 3 x 25mm end cap 4 x 25mm saddle clamp 4 x 32mm pipe, 1m 4 x 32mm elbow 90° (short radius) 1 x 32mm tee 1 x 32mm end cap 2 x 32mm coupler 4 x Cardboard blank (sheet) 4 x Zip ties (pack of 10) 1 x Fevicol 1 x Scissors 1 x Duct tape 2 x A3 sheets 1 x Permanent pen tip marker 1 x Rubber mallet 1 x Ball 12 mm
3 | 24 x 25mm pipe, 1m 12 x 25mm three-way corner (PVC furniture fittings) 4 x 25mm four-way corner (PVC furniture fittings) 8 x 25mm tee 6 x 25mm elbow 90° 8 x 25mm coupler 8 x 25mm end cap 5 x 25mm saddle clamp 4 x 32mm pipe, 1m 2 x 32mm elbow 90° (short radius) 3 x 32mm bend 45° 1 x 32mm tee 1 x 32mm end cap 3 x 76mm split channel, 1m (SWR Type B) 2 x 76mm split bend 90° (SWR Type B) 1 x Zip ties (pack of 10) 2 x A3 sheets 1 x Permanent pen tip marker 1 x Rubber mallet 1 x Ball 25 mm
4 | 14 x 25mm pipe, 1m 6 x 25mm three-way corner (PVC furniture fittings) 5 x 25mm tee 3 x 25mm elbow 90° 3 x 25mm coupler 3 x 25mm end cap 5 x 25mm saddle clamp 3 x 32mm pipe, 1m 2 x 32mm elbow 90° (short radius) 1 x 32mm tee 1 x 32mm end cap 1 x 76mm split channel, 1m (SWR Type B) 1 x 76mm split bend 90° (SWR Type B) 2 x Cardboard blank (sheet) 2 x Zip ties (pack of 10) 1 x Dowel pack 2 x A3 sheets 1 x Permanent pen tip marker 1 x Rubber mallet 1 x Ball 12 mm
5 | 14 x 25mm pipe, 1m 6 x 25mm three-way corner (PVC furniture fittings) 5 x 25mm tee 3 x 25mm elbow 90° 3 x 25mm coupler 3 x 25mm end cap 4 x 25mm saddle clamp 2 x 32mm pipe, 1m 2 x 32mm bend 90° (long radius) 2 x 32mm Y junction 1 x 32mm end cap 1 x 76mm split channel, 1m (SWR Type B) 8 x Cardboard blank (sheet) 4 x Zip ties (pack of 10) 3 x Fevicol 3 x Scissors 3 x Duct tape 2 x A3 sheets 1 x Permanent pen tip marker 1 x Rubber mallet 1 x Ball 25 mm
6 | 6 x 25mm pipe, 1m 2 x 25mm three-way corner (PVC furniture fittings) 2 x 25mm tee 1 x 25mm elbow 90° 1 x 25mm coupler 1 x 25mm end cap 2 x 25mm saddle clamp 1 x 32mm pipe, 1m 1 x 32mm elbow 90° (short radius) 1 x 32mm tee 1 x Cardboard blank (sheet) 1 x Zip ties (pack of 10) 2 x A3 sheets 1 x Permanent pen tip marker 1 x Rubber mallet 1 x Ball 12 mm
7 | 8 x 25mm pipe, 1m 10 x 25mm three-way corner (PVC furniture fittings) 3 x 25mm four-way corner (PVC furniture fittings) 4 x 25mm tee 4 x 25mm elbow 90° 6 x 25mm coupler 2 x 25mm end cap 14 x 25mm saddle clamp 2 x 32mm bend 45° 2 x 32mm tee 2 x 32mm end cap 6 x 32mm coupler 4 x 32mm × 25mm reducer bush 2 x Split foam insulation, 1m 6 x Zip ties (pack of 10) 2 x A3 sheets 1 x Permanent pen tip marker 1 x Rubber mallet 1 x Ball 25 mm
8 | 16 x 25mm pipe, 1m 6 x 25mm three-way corner (PVC furniture fittings) 6 x 25mm tee 4 x 25mm elbow 90° 3 x 25mm coupler 4 x 25mm end cap 6 x 25mm saddle clamp 3 x 32mm pipe, 1m 1 x 32mm bend 90° (long radius) 2 x 32mm elbow 90° (short radius) 1 x 32mm tee 1 x 32mm end cap 2 x 76mm split channel, 1m (SWR Type B) 1 x 76mm split bend 90° (SWR Type B) 3 x Cardboard blank (sheet) 3 x Zip ties (pack of 10) 1 x Sensor module 2 x A3 sheets 1 x Permanent pen tip marker 1 x Rubber mallet 1 x Ball 12 mm
9 | 14 x 25mm pipe, 1m 5 x 25mm three-way corner (PVC furniture fittings) 5 x 25mm tee 3 x 25mm elbow 90° 2 x 25mm coupler 3 x 25mm end cap 5 x 25mm saddle clamp 3 x 32mm pipe, 1m 3 x 32mm elbow 90° (short radius) 1 x 76mm split channel, 1m (SWR Type B) 5 x Flexible borewell hose, 1m 4 x Split foam insulation, 1m 2 x Zip ties (pack of 10) 1 x Sensor module 2 x A3 sheets 1 x Permanent pen tip marker 1 x Rubber mallet 1 x Ball 25 mm
10 | 20 x 25mm pipe, 1m 7 x 25mm three-way corner (PVC furniture fittings) 3 x 25mm four-way corner (PVC furniture fittings) 4 x 25mm tee 3 x 25mm elbow 90° 2 x 25mm coupler 3 x 25mm end cap 9 x 25mm saddle clamp 8 x 32mm pipe, 1m 1 x 32mm bend 90° (long radius) 2 x 32mm elbow 90° (short radius) 1 x 32mm tee 2 x 32mm end cap 2 x 76mm split channel, 1m (SWR Type B) 2 x 76mm split bend 90° (SWR Type B) 3 x Cardboard blank (sheet) 2 x Zip ties (pack of 10) 1 x Fevicol 1 x Duct tape 2 x Narrow bucket / paper cup 2 x A3 sheets 1 x Permanent pen tip marker 1 x Rubber mallet 1 x Ball 12 mm 1 x Ball 25 mm

# Basekit Materials — Total Quantity Required

Item | Basekit Total | Depot Stock | Total Available
25mm pipe, 1m | 154 | 231 | 385
25mm three-way corner | 68 | 102 | 170
25mm four-way corner | 17 | 26 | 43
25mm tee | 51 | 77 | 128
25mm elbow 90° | 34 | 51 | 85
25mm coupler | 34 | 51 | 85
25mm end cap | 34 | 51 | 85
25mm saddle clamp | 60 | 90 | 150
32mm pipe, 1m | 30 | 45 | 75
32mm bend 90° (long radius) | 4 | 32 | 36
32mm elbow 90° (short radius) | 20 | 30 | 50
32mm bend 45° | 5 | 25 | 30
32mm Y junction | 2 | 4 | 6
32mm tee | 10 | 15 | 25
32mm end cap | 10 | 15 | 25
32mm coupler | 10 | 30 | 40
32mm × 25mm reducer bush | 4 | 12 | 16
76mm split channel, 1m (SWR Type B) | 10 | 15 | 25
76mm split bend 90° (SWR Type B) | 6 | 9 | 15
Flexible borewell hose, 1m | 5 | 11 | 16
Split foam insulation, 1m | 6 | 10 | 16
Cardboard blank (sheet) | 23 | 67 | 90
Zip ties (pack of 10) | 26 | 39 | 65
Fevicol | 5 | 15 | 20
Scissors | 4 | 16 | 20
Duct tape | 6 | 34 | 40
Elastic cord set | 2 | 6 | 8
Dowel pack | 3 | 9 | 12
Narrow bucket / paper cup | 2 | 3 | 5
Sensor module | 2 | 3 | 5
A3 sheets | 20 | 30 | 50
Permanent pen tip marker | 10 | 15 | 25
Rubber mallet | 10 | 15 | 25
Ball 12 mm | 6 | — | 6
Ball 25 mm | 6 | — | 6
Total pieces | 699 | 1184 | 1883

# Materials (Depot)

MOQ 1 on every line. All prices are multiples of 20 so the 50% buyback is always payable in coins. Stock is sized for a remote venue with no resupply: at least 2x estimated consumption on every line. Structural 25mm/15kg · Pathway 32mm/10kg · Open split channel 76mm SWR Type B.

Item | MOQ | Stock Qty | Initial Price | Buyback 50%

STRUCTURAL — 25mm OD, 15kg (supports and frames)
25mm pipe, 1m | 1 | 231 | 60 | 30
25mm three-way corner (PVC furniture fittings) | 1 | 102 | 60 | 30
25mm four-way corner (PVC furniture fittings) | 1 | 26 | 80 | 40
25mm tee | 1 | 77 | 40 | 20
25mm elbow 90° | 1 | 51 | 40 | 20
25mm coupler | 1 | 51 | 20 | 10
25mm end cap | 1 | 51 | 20 | 10
25mm saddle clamp | 1 | 90 | 40 | 20

PATHWAY CLOSED — 32mm OD, 10kg (ID ≈ 28mm)
32mm pipe, 1m | 1 | 45 | 200 | 100
32mm coupler | 1 | 30 | 60 | 30
32mm elbow 90° (short radius) | 1 | 30 | 100 | 50
32mm bend 90° (long radius) | 1 | 32 | 300 | 150
32mm bend 45° | 1 | 25 | 180 | 90
32mm tee | 1 | 15 | 140 | 70
32mm Y junction | 1 | 4 | 220 | 110
32mm end cap | 1 | 15 | 40 | 20
32mm × 25mm reducer bush | 1 | 12 | 120 | 60

PATHWAY OPEN — 76mm split, SWR Type B
76mm split channel, 1m (SWR Type B) | 1 | 15 | 200 | 100
76mm split bend 90° (SWR Type B) | 1 | 9 | 240 | 120

FLEX & FRICTION
Flexible borewell hose, 1m | 1 | 11 | 300 | 150
Split foam insulation, 1m | 1 | 10 | 120 | 60

CONSUMABLES
Cardboard blank (sheet) | 1 | 67 | 120 | 60
Zip ties (pack of 10) | 1 | 39 | 80 | 40
Fevicol | 1 | 15 | 200 | 100
Scissors | 1 | 16 | 240 | 120
Duct tape | 1 | 34 | 160 | 80
Elastic cord set | 1 | 6 | 140 | 70
Dowel pack | 1 | 9 | 100 | 50
Permanent pen tip marker | 1 | 15 | 60 | 30
Rubber mallet | 1 | 15 | 300 | 150
Funnel | 1 | 8 | 200 | 100
Narrow bucket / paper cup | 1 | 3 | 100 | 50
A3 sheets | 1 | 30 | 20 | 10

SPECIAL
Sensor module | 1 | 3 | 200 | 100

# Facilitator Spares — carry to site, not sold at the depot

Item | Qty | Why
Ball 12 mm | 20 | Small balls roll away and vanish. Losing them ends the event
Ball 25 mm | 20 | Same, plus these double as clearance gauges
Clearance gauge (ball on dowel) | 10 | One per team. Size to the Path A ceiling once decided
Sensor module | 5 | 2 in use, 3 spare. No resupply for electronics
Buckets (final target) | 4 | 2 in use, 2 spare
Frame ballast (sandbag / weight) | 10 sets | A 2m PVC tower rocks; Team 2's climb needs a rigid base
Solvent cement | 4 | Not in kits — issue only if a team asks
First aid kit | 2 | Power tools and hacksaws, 60 people

Sizing rule: depot stock is the greater of 1.5x basekit quantity, or enough to bring total availability to twice estimated consumption. Every line is at or above 2x. Structural sits at 2.1x, pathway bends at 2.0x, consumables at 2.0-2.2x.

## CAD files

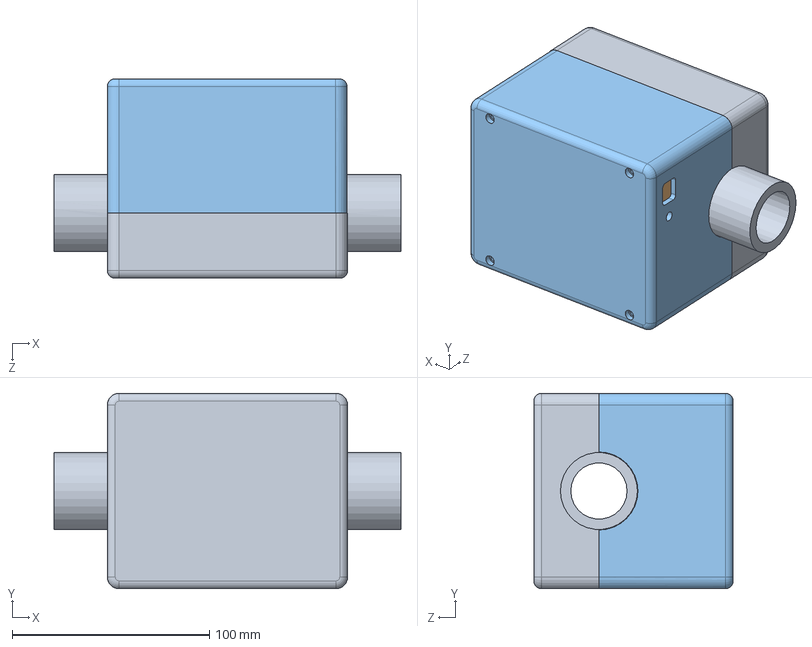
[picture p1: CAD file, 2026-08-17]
hardware/Assem1.SLDASM
175.7 x 99.0 x 101.0 mm
Bottom case
Electronics Block
top case

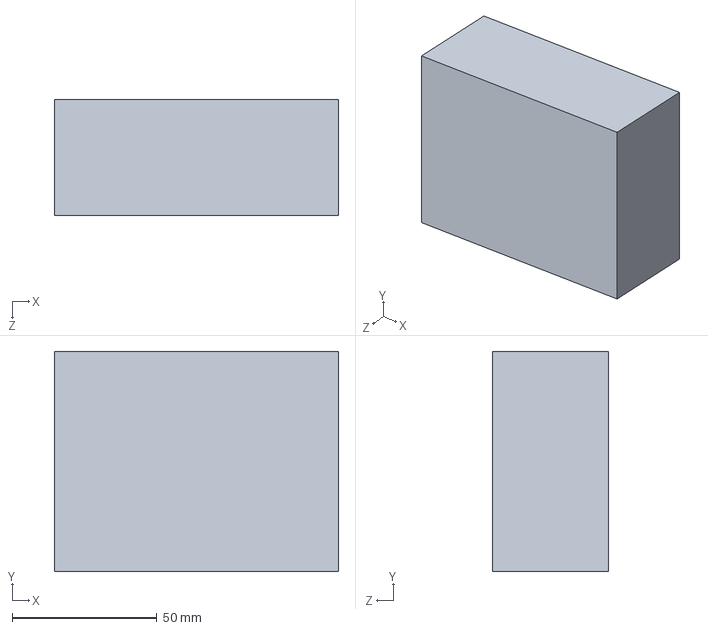
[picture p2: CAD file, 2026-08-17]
hardware/Electronics Block.SLDPRT
98.0 x 76.0 x 40.0 mm

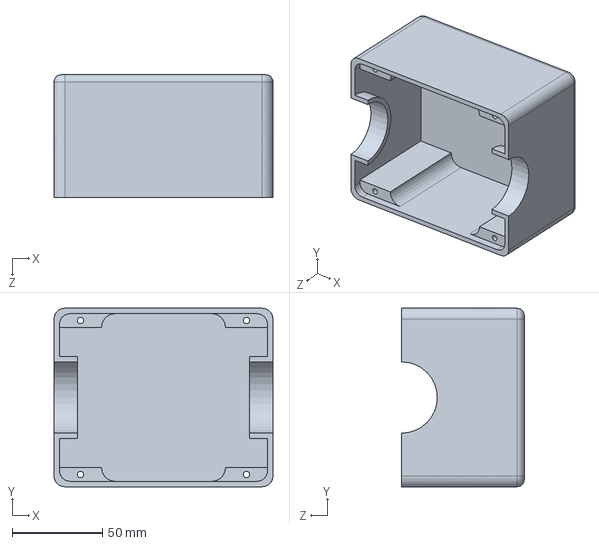
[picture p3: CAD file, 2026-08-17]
hardware/Bottom case.SLDPRT
121.4 x 99.0 x 68.0 mm

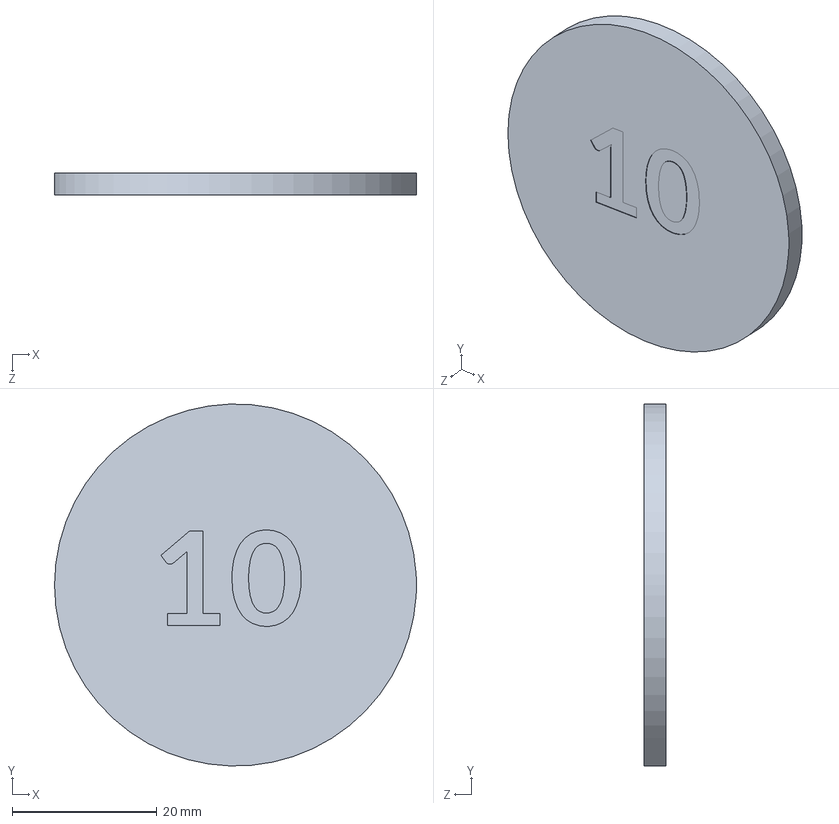
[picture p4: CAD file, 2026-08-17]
openmarket/TASL_coins_10.SLDPRT
50.0 x 50.0 x 3.00 mm

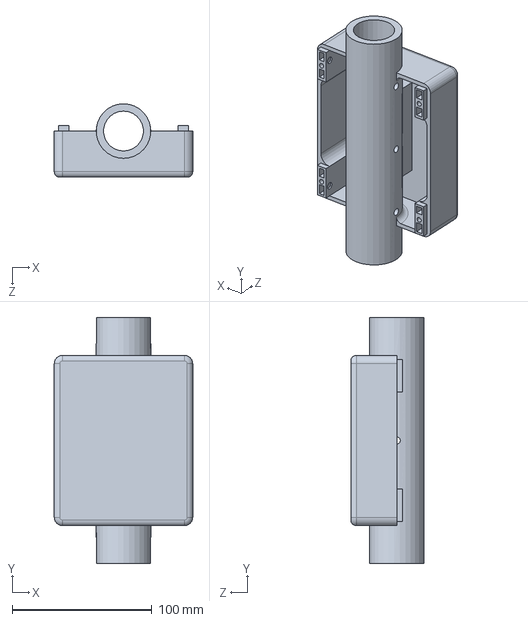
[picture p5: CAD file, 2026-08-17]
hardware/top case.SLDPRT
99.0 x 175.7 x 52.5 mm

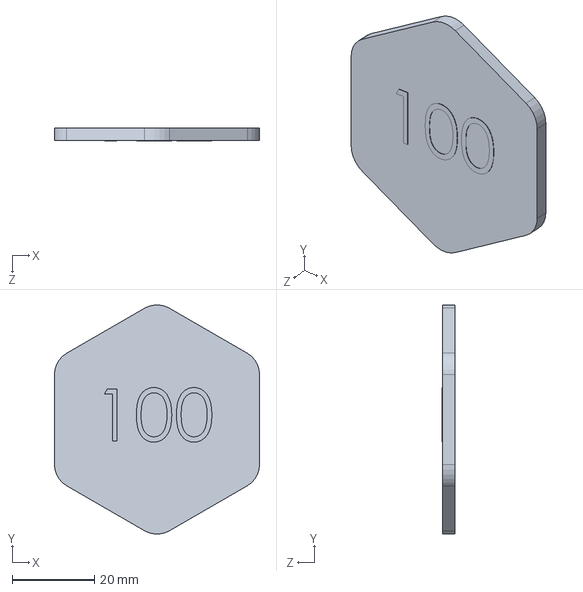
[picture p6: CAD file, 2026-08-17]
openmarket/TASL_hex coins_100.SLDPRT
50.0 x 55.8 x 3.10 mm

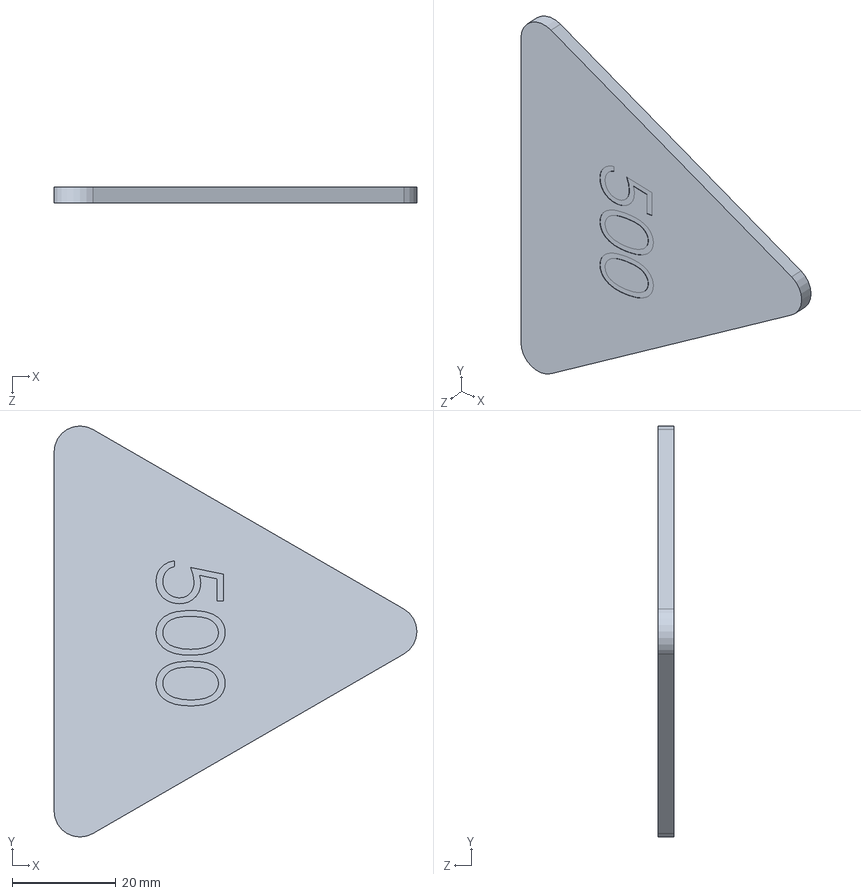
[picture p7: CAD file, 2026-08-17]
openmarket/TASL_triangular coins_500.SLDPRT
70.0 x 79.3 x 3.00 mm

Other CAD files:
openmarket/TASL COINS V1.DXF
openmarket/TASL_coins_20.SLDPRT
openmarket/TASL_coins_100.SLDPRT
openmarket/TASL_coins_50.SLDPRT
hardware/Bottom case.STL
hardware/top case.STL
openmarket/TASL COINS V1.SLDDRW

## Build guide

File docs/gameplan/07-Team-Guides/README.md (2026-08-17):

# Team Guide Books

Ten participant books, one per team — challenge, kit contents, coins, depot price list, rules, trade log.

**Status: needs regenerating.** The drafts built earlier in the session use inch sizing, the old price list, and items since removed. They are not in this folder because they would be misleading.

Regenerate once these close:

- Path A ball ceiling, and therefore the clearance gauge size
- 32mm vs 40mm closed pathway
- Team 5 wording — minimum or maximum gap

Each book carries the depot price list, so any price change means reprinting all ten.

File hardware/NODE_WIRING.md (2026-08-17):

# TASL sensor node — complete wiring reference

One node = one measurement station = **two IR beams** a known distance apart,
on an **ESP32 DevKit V1 (30-pin)**, battery powered, in a 3D-printed housing.

This document covers the **final** node, including everything: IR sensors,
LiPo, TP4056 charger, power switch, RGB status LED and battery sensing. Build
it in stages (see *Build order*), but solder the layout for the finished thing
so you're not reworking 20 boards later.

You do your own track routing. This gives you every connection, every pin.

---

## 1. Battery sizing — 500 mAh vs 1000 mAh

### The current budget

| Load | Current @ 3.3 V |
|---|---|
| ESP32 + Wi-Fi, average | 45 – 100 mA |
| IR emitter, beam A (20 mA) | 20 mA |
| IR emitter, beam B (20 mA) | 20 mA |
| Two phototransistors | ~2 mA |
| RGB LED, one colour | 3 mA |
| Battery divider | 0.02 mA |
| **Total average** | **90 – 145 mA** |

The ESP32 figure is a genuine range, not hedging. With Wi-Fi modem sleep
active it idles near 45 mA; with it disabled, over 100 mA. Which one you get
depends on the core version's defaults, so **it has to be measured, not
assumed.**

Through the boost + onboard regulator at ~72% efficiency, that's **110 – 180 mA
drawn from the cell**.

### Runtime

| Cell | Worst case | Likely | With the easy wins below |
|---|---|---|---|
| **500 mAh** | 2.8 h | 4.5 h | ~6.5 h |
| **1000 mAh** | 5.5 h | 9 h | ~13 h |
| 2000 mAh | 11 h | 18 h | ~26 h |

### The requirement: a 4-hour event needs ~6 hours of cell

The event runs **4 hours**. The nodes are powered for longer than that: setup,
teams building their sections, dry runs, the run itself, teardown. Design for
**6 hours of switch-on time**, not 4.

Two derates nobody accounts for:

- **You can't use the last of the cell.** Below ~3.5 V the node is in RED and
  you'd swap it. Call it 85% usable.
- **Cheap cells are overstated.** A generic "1000 mAh" is often 700–800 mAh
  real. On a 500 mAh cell that leaves you working with ~400.

### Verdict: go to 1000 mAh

**1000 mAh clears the 6-hour requirement even in the worst case**, and with the
two free firmware wins below it reaches ~13 h and stops being something you
think about. You don't need 2000 mAh, and the smaller cell fits a smaller
housing.

Three things make battery life a non-issue rather than a risk:

1. **Use the switch.** The SPST isn't decoration — it's the battery strategy.
   Nodes don't need to be on while teams are still cutting pipe. Switch on
   30 minutes before the first run and the 6-hour requirement drops to ~4.5.
2. **Charge spares.** JST-XH means a swap takes ten seconds.
3. **A flat cell isn't a failure.** The dashboard turns that node yellow, then
   red, then flashing, well before it dies. You swap it in a natural pause.
   That's the whole reason the battery indicator exists.

**500 mAh is the one to avoid.** Its worst case is 2.8 hours, which is roughly
"the event, if nothing goes wrong and every cell started full." That's not a
margin, that's a hope. And you'd have to modify all 20 TP4056 modules
(§1.3 below).

### 1.2 What about 2× 500 mAh in parallel?

Electrically it's fine — capacity adds, voltage stays at 3.7 V, and the TP4056
and protection circuit see one 1000 mAh pack. Stock 1000 mA charge is 1C,
exactly as with a single cell.

**For a 20-node build it's still the wrong call**, for practical reasons:

| | 2× 500 mAh | 1× 1000 mAh |
|---|---|---|
| Cells to buy, charge, track | **40** | 20 |
| Solder joints in the power path | **40** | 20 |
| Voltage-matching procedure | 20× | none |
| Physical volume | **larger** — two cases, two sets of tabs | smaller |
| Cost | usually **more** | less |

Every extra joint across 20 nodes is another intermittent-fault candidate, and
intermittent power faults are the hardest class to diagnose at an event.

> **⚠ The genuine hazard: never join two cells at different states of charge.**
> Internal resistance is ~50–100 mΩ, so connecting a 4.2 V cell to a 3.6 V one
> gives `(4.2 − 3.6) / 0.15 Ω ≈ 4 A` instantaneously, through cells rated for a
> fraction of that. It damages cells and can start a fire.

**If you already own 40× 500 mAh cells**, do it like this:

1. Charge **each cell individually** to full first.
2. Meter both — **within 50 mV** before they touch.
3. Same brand, same batch, same age. Never pair a new cell with a used one.
4. Solder them permanently in parallel and treat the pair as **one sealed
   pack**. The danger is repeated connect/disconnect at differing charge, so
   design that possibility out.
5. Both positives to one point, both negatives to another, then a single
   JST-XH-2 to the board.
6. Charge as one 1000 mAh pack — stock TP4056 is correct.

### 1.3 Charge current

The TP4056's charge current is set by `R_prog`, and should be **0.5C to 1C**.

| Cell | Stock 1.2 kΩ = 1000 mA | Action |
|---|---|---|
| 500 mAh | 2C — **too fast** | Must change to 4 kΩ (≈300 mA) on all 20 |
| 1000 mAh | 1C — acceptable | Leave stock, or 2 kΩ (580 mA) to be gentle |
| 2000 mAh | 0.5C — ideal | Leave stock |
| **3000 mAh** (as built) | **0.33C — ideal** | **Leave stock. No module modification needed** |

The 3000 mAh cell also takes battery runtime off the risk list entirely:
roughly **17–27 hours** at the 110–180 mA the node draws, against a 6-hour
switch-on requirement. Charging one from empty at 1000 mA takes about 3.5 hours,
so charge overnight rather than between runs.

1C on a 1000 mAh cell is within spec for modern LiPos. It shortens cycle life
slightly, which is irrelevant over the ~20 charges this project will ever see.

### 1.4 Easy wins, in order of value

Apply these before deciding you need a bigger cell.

| Change | Saves | Cost to you |
|---|---|---|
| **Confirm Wi-Fi modem sleep is on** — `WiFi.setSleep(true)` | up to 55 mA | One line. Doesn't affect outgoing events, which is all we send |
| **CPU to 80 MHz** — `setCpuFrequencyMhz(80)` | ~20 mA | One line. Wi-Fi and `micros()` timing both unaffected |
| **IR emitters at 10 mA** — 200 Ω instead of 100 Ω | 20 mA | Resistor swap. Fine with a tight aperture and a black shroud; test alignment first |
| **Flash the RGB LED** instead of solid on | ~3 mA | Small firmware change. Also easier to read across a hall |

Together these roughly halve consumption. The first two are free and carry no
real downside.

> **Not worth it:** strobing the IR emitters at 10 kHz with synchronous
> sampling would cut emitter current by ~90%, but it complicates the timing
> path — the one part of this system that must not be clever.

### 1.5 Measure it before you commit

Every number above is calculated, not measured. Once **stage 1** of the build
works, put a multimeter in series with the battery and read the actual current.
Ten minutes, and it replaces this entire section with a fact.

If it comes in near 90 mA, a 500 mAh cell would genuinely last ~4.5 h and you
could keep them. If it's near 145 mA, you'll be glad you went to 1000 mAh.

### 1.6 The cheap insurance

You're using JST-XH connectors, so **swapping a cell takes ten seconds**.
Charge a set of spares and keep them in the toolbox. That, plus the dashboard
turning a node's battery icon red before it dies, means a flat cell is a
30-second interruption rather than a failure.

---

## 2. Power architecture

The single most important decision, and the one most likely to destroy an
ESP32 if you get it wrong.

```
LiPo ──> TP4056 ──> SPST ──> MT3608 ──> AMS1117 ──> ESP32 3V3 pin
3000mAh  +protect   switch   boost 5V    3.3V       (VIN unused)
                                            │
                                       1000 µF 16V
```

**This is the as-built chain.** It differs from the original design in §2.1
below: an external AMS1117 feeds the **`3V3` pin** directly and the ESP32's
onboard regulator is bypassed, so `VIN` is left disconnected. The sensors get
the same clean rail as the ESP32.

The rule that follows: **switch OFF before plugging in USB**, every time. With
the `3V3` pin driven externally there is no diode protecting you from two
supplies fighting.

### Why not simpler?

**Can the LiPo feed VIN directly?** No. `VIN` goes through the onboard
AMS1117 regulator, which needs ~1.1 V of headroom — so at least 4.4 V in. A
LiPo starts at 4.2 V and falls. It would brown out immediately.

**Can the LiPo feed the 3V3 pin directly?** No, and this one kills boards. The
3V3 pin sits straight on the 3.3 V rail. A charged LiPo at 4.2 V is **0.9 V
over** what the ESP32 is rated for.

**Can an LM2596 step 3.7 V down to 3.3 V for VIN?** No — it fails twice over.

1. **The LM2596 is a buck (step-down) converter, and its datasheet minimum
   input is 4.5 V.** A 3.7 V cell is already below that, so it won't even
   start. And a buck can never produce 3.3 V from a cell that sags to 3.0 V —
   that's physics, not a tuning problem.
2. **3.3 V into `VIN` does nothing useful anyway.** `VIN` feeds the onboard
   AMS1117, which needs ~4.4 V. Give it 3.3 V and the 3.3 V rail comes out at
   roughly 2.2 V. The ESP32 won't run.

If you want 3.3 V it has to go to the **`3V3` pin**, bypassing the onboard
regulator — and to make 3.3 V across the cell's whole 4.2 → 3.0 V range you
need a **buck-boost**, not a buck. The LM2596 also idles at 5–10 mA, which is
most of a phototransistor's budget wasted continuously.

**So:** boost the LiPo to a steady 5 V and feed `VIN`. The onboard regulator
then does what it was designed to do. Costs some efficiency, but it works over
the cell's whole range and is very hard to get wrong.

### 2.1 If you want the extra runtime: buck-boost to 3V3

There is a better-but-pricier option. A **TPS63020-based buck-boost module**
set to 3.3 V, feeding the **`3V3` pin** directly, skips the onboard regulator
entirely.

| | MT3608 boost → `VIN` | TPS63020 buck-boost → `3V3` |
|---|---|---|
| Efficiency | ~72% (two conversions) | ~90% (one) |
| Runtime, 1000 mAh | 5.5 – 9 h | **7 – 12 h** |
| Cost | ~₹30 | ~₹150–250 |
| Risk if mis-set | Destroys the ESP32 | Destroys the ESP32 |
| Complexity | Lower | Slightly higher |

Both need the same care: **set the output voltage with a meter, on no load,
before it ever touches the board.** The switch still goes before the module,
and the USB rule is unchanged.

Use the MT3608 unless the battery budget turns out tight after you measure
(§1.5). It's the simpler part, and simpler wins on a 20-node build.

### ⚠ Adjust every MT3608 before it ever touches an ESP32

MT3608 modules are **adjustable and ship at an arbitrary setting**. The pot can
output up to 28 V. Connecting an unadjusted one to `VIN` can destroy the board
instantly.

For every module, in this order:

1. Connect the module's input to the battery (or any 3.7–4.2 V source).
2. **Nothing connected to the output.**
3. Multimeter on the output pads.
4. Turn the pot until it reads **5.0 V**. Many turns — it's a multi-turn pot.
5. Disconnect, then wire it to the ESP32.
6. Put a dab of nail varnish or hot glue on the pot so it can't drift.

Do this for all 20 before you solder any of them in.

### ⚠ Switch the node OFF before plugging in USB

With the node powered from the battery, the boost drives `VIN` while USB
drives the 5 V rail. They'll fight. The SPST switch sits *before* the boost, so
switching off disconnects it completely.

**Rule: switch OFF → then plug in USB.** Every time.

### Charging

The switch is between `OUT+` and the boost, so the TP4056 charges the cell
through `B+`/`B−` regardless of switch position. **Charging works with the node
switched off**, which is what you want overnight.

---

## 3. Bill of materials — ONE node

| # | Part | Value / spec | Notes |
|---|---|---|---|
| 1 | ESP32 DevKit V1 | 30-pin DOIT | Not the 36-pin DevKitC — pin positions differ |
| 2 | TP4056 module | **with protection** | Must have DW01A + 8205A chips. See §7 |
| 3 | MT3608 boost module | adjustable | Set to 5.0 V *before* connecting |
| 4 | 1S LiPo | 3.7 V **3000 mAh** | With JST connector. See §1 — 1000 mAh was the original spec, 3000 mAh is what the build actually uses |
| 5 | SPST switch | any, ≥500 mA | Slide or toggle |
| 6 | IR LED, 940 nm | 5 mm clear | ×2 (one per beam) |
| 7 | IR phototransistor | 5 mm dark/black | ×2 (one per beam) |
| 8 | RGB LED | 5 mm, 4-pin, **common cathode**, diffused | Diffused matters — clear ones are hard to read off-axis |
| 9 | Resistor **220 Ω** | ¼ W | ×2 — IR emitter current limit (in cartridges). **Bench-proven value**, see §8 |
| 10 | Resistor **100 kΩ** | ¼ W | ×2 — phototransistor pull-downs. **Bench-proven value**, see §8 |
| 11 | Resistor 100 kΩ | ¼ W, 1% | ×2 — battery divider |
| 12 | Resistor 330 Ω | ¼ W | ×1 — RGB red |
| 13 | Resistor 150 Ω | ¼ W | ×2 — RGB green, blue |
| 14 | Capacitor 100 nF | ceramic | ×1 — ADC filter |
| 15 | Capacitor **1000 µF** | electrolytic, **16 V** | ×1 — bulk, across 3V3/GND, close to the ESP32 |
| 15b | **AMS1117-3.3** regulator | SOT-223 module or bare | ×1 — 5 V from the boost down to a clean 3V3 rail. See §2.2 |
| 16 | JST-XH 2-pin | male + female | Battery to board |
| 17 | JST-XH 3-pin | male + female | ×2 — one per beam cartridge |
| 18 | Perfboard | | |

**1% resistors for the divider (item 11)** — the divider ratio directly sets
your battery reading, and 5% parts give you Â±5% error on a measurement whose
whole job is distinguishing 3.65 V from 3.80 V.

---

## 4. GPIO allocation — ESP32 DevKit V1

| GPIO | Silkscreen | Function | Why this pin |
|---|---|---|---|
| **19** | `D19` | Beam A signal | Digital-only, right-hand header. Chosen so both beams land on the same side as the sensor cable run |
| **18** | `D18` | Beam B signal | Same |
| **34** | `D34` | Battery sense | ADC1, input-only — perfect for analog, needs no pull-up |
| **25** | `D25` | RGB red | Safe output, no strapping conflict |
| **26** | `D26` | RGB green | " |
| **27** | `D27` | RGB blue | " |
| 2 | `D2` | Onboard blue LED | Already used by firmware for status |
| 0 | `BOOT` btn | Test/align button | Onboard, no wiring needed |

The battery sense and RGB LED are on the **left-hand header**; the two beams
are on the **right**, next to each other, so the sensor cables leave the board
on one side.

### Why ADC1 and not ADC2 — battery sense only

**ADC2 stops working the moment Wi-Fi is active.** It's shared with the radio.
Since every node runs Wi-Fi permanently, ADC2 is unusable for analog. GPIO32–39
are ADC1 and unaffected, which is why battery sense sits on GPIO34.

### Pins to avoid

- **GPIO6–11** — wired to the onboard SPI flash. Using them bricks the boot.
- **GPIO12** — strapping pin; held high at boot stops the board starting.
- **GPIO34–39** — input-only, and no internal pull-ups. Fine for our ADC use,
  useless for driving anything.
- **GPIO1, GPIO3** — TX0/RX0. Using them breaks upload and the Serial Monitor.
- **GPIO15** — strapping pin.

### The beams are digital-only, and that is fine

Ball timing uses **digital reads** — fast, deterministic edges, which is what
accurate timing needs. GPIO19 and GPIO18 are not ADC-capable, so they cannot do
the analog *alignment* readout.

That costs nothing in practice: alignment is a bench operation, done once per
cartridge with the standalone `firmware/tasl_beam_align` sketch before the
sensors go on the track. Run that sketch in digital mode (`BEAM_ANALOG 0`) and
break the beam with a finger — the break counter tells you whether the beam is
reliable, which is the question that actually matters.

If you want the raw analog margin while aiming a difficult cartridge, move that
one beam's wire to **GPIO32** temporarily, set `BEAM_ANALOG 1`, aim it, then put
it back on GPIO19.

---

## 5. Net table

Every connection on the board. Grouped by net — everything in one block is
electrically the same node.

### NET: `BAT+` — raw cell positive
| From | To |
|---|---|
| LiPo red wire | JST-XH-2 **pin 1** |
| JST-XH-2 **pin 1** | TP4056 `B+` pad |

### NET: `BAT−` — raw cell negative
| From | To |
|---|---|
| LiPo black wire | JST-XH-2 **pin 2** |
| JST-XH-2 **pin 2** | TP4056 `B−` pad |

### NET: `VBAT_RAW` — protected battery output
| From | To |
|---|---|
| TP4056 `OUT+` | SPST switch, terminal 1 |

### NET: `VBAT_SW` — after the switch
| From | To |
|---|---|
| SPST switch, terminal 2 | MT3608 `IN+` |
| SPST switch, terminal 2 | R11a (100 kΩ), leg 1 |

*The divider hangs off the switched side, so it draws nothing when the node is
off.*

### NET: `+5V` — boost output
| From | To |
|---|---|
| MT3608 `OUT+` | AMS1117 **`IN`** |

*ESP32 `VIN` is **not** connected. The onboard regulator is bypassed.*

### NET: `+3V3` — regulated rail (output from the external AMS1117)
| From | To |
|---|---|
| AMS1117 **`OUT`** | ESP32 **`3V3`** pin |
| AMS1117 **`OUT`** | Beam A JST-XH-3 **pin 1** |
| AMS1117 **`OUT`** | Beam B JST-XH-3 **pin 1** |
| AMS1117 **`OUT`** | C15 (1000 µF) **+** leg |

*Put C15 physically as close to the ESP32's `3V3`/`GND` pins as you can — it is
there to supply the ~250 mA Wi-Fi transmit spike, and track resistance between
the cap and the chip defeats the purpose.*

### NET: `GND` — common ground (all of these tie together)
| Connection |
|---|
| TP4056 `OUT−` |
| MT3608 `IN−` |
| MT3608 `OUT−` |
| AMS1117 **`GND`** |
| ESP32 **`GND`** (either pin) |
| RGB LED **common cathode** |
| Beam A JST-XH-3 **pin 3** |
| Beam B JST-XH-3 **pin 3** |
| R11b (100 kΩ) leg 2 — divider bottom |
| C14 (100 nF) leg 2 |
| R10a (100 kΩ) leg 2 — beam A pull-down |
| R10b (100 kΩ) leg 2 — beam B pull-down |
| C15 (1000 µF) **−** leg |

**One ground, everything on it.** A node with a floating ground between the
boost and the ESP32 gives bizarre, intermittent faults that look like sensor
problems.

### NET: `BATT_SENSE` → GPIO34
| From | To |
|---|---|
| R11a (100 kΩ) leg 2 | R11b (100 kΩ) leg 1 |
| that junction | ESP32 **`D34`** |
| that junction | C14 (100 nF) leg 1 |

### NET: `BEAM_A_SIG` → GPIO19
| From | To |
|---|---|
| Beam A JST-XH-3 **pin 2** | ESP32 **`D19`** |
| Beam A JST-XH-3 **pin 2** | R10a (100 kΩ) leg 1 |

### NET: `BEAM_B_SIG` → GPIO18
| From | To |
|---|---|
| Beam B JST-XH-3 **pin 2** | ESP32 **`D18`** |
| Beam B JST-XH-3 **pin 2** | R10b (100 kΩ) leg 1 |

### NET: `LED_R` / `LED_G` / `LED_B`
| From | To |
|---|---|
| ESP32 **`D25`** | R12 (330 Ω) → RGB **red** anode |
| ESP32 **`D26`** | R13 (150 Ω) → RGB **green** anode |
| ESP32 **`D27`** | R13b (150 Ω) → RGB **blue** anode |

---

## 6. JST-XH pinout cards

Print these. Getting a battery backwards destroys things.

### Battery — JST-XH **2-pin**

```
        â”Œ─────────â”
        â”‚  1   2  â”‚
        â””─â”¬─────â”¬─â”˜
          â”‚     â”‚
        RED   BLACK
        BAT+   BAT−
       (to     (to
       TP4056  TP4056
        B+)     B−)
```

| Pin | Signal | Wire |
|---|---|---|
| 1 | `BAT+` | **Red** |
| 2 | `BAT−` | **Black** |

> **Check with a multimeter before every first connection.** LiPo cells ship
> with varying connector orientations, and reversing one can vent the cell.

### IR beam cartridge — JST-XH **3-pin** (×2, identical)

```
        â”Œ───────────â”
        â”‚  1  2  3  â”‚
        â””─â”¬──â”¬──â”¬───â”˜
          â”‚  â”‚  â”‚
        RED YEL BLK
        3V3 SIG GND
```

| Pin | Signal | Wire | Goes to |
|---|---|---|---|
| 1 | `+3V3` | Red | IR LED anode (via 220 Ω) **and** phototransistor collector |
| 2 | `SIGNAL` | Yellow | Phototransistor emitter |
| 3 | `GND` | Black | IR LED cathode |

**Both cartridges are wired identically** — beam A and beam B are
interchangeable, so a spare fits either socket. Only the board-side connector
decides which is which.

### Inside one cartridge

The **220 Ω resistor lives in the cartridge**, not on the board. That's what
gets each beam down to three wires instead of four.

```
  pin 1 (3V3) ──â”¬── [220 Ω] ── IR LED anode
                â”‚                 IR LED cathode ── pin 3 (GND)
                â”‚
                â””── phototransistor COLLECTOR
                    phototransistor EMITTER ────── pin 2 (SIGNAL)
```

The 100 kΩ pull-down stays on the **main board**, so you can change sensitivity
without opening a sealed cartridge.

---

## 7. Identifying component pins

Don't trust leg length alone — test.

### TP4056 — is it the protected version?

**Critical.** The unprotected version has no over-discharge cutoff and will
flatten a LiPo until it's damaged and potentially unsafe.

Look at the board. The **protected** version has **three** ICs:
- `TP4056` — the charge controller
- `DW01A` — protection controller (6-pin, near the `B−` pad)
- `8205A` — dual MOSFET (8-pin, beside the DW01A)

Only the TP4056 chip and no others → **unprotected, don't use it.**

Pads: `IN+`/`IN−` (or micro-USB), `B+`/`B−` (cell), `OUT+`/`OUT−` (load).

### IR phototransistor — which leg is the collector?

Convention is unreliable across manufacturers. Test it:

1. Wire the suspected **collector to 3V3**, **emitter through 100 kΩ to GND**.
2. Multimeter on the emitter leg (relative to GND).
3. Point a TV remote at it and press a button.
4. **Voltage rises** → correct. **Nothing happens** → swap the legs.

Bare phototransistors are IR-sensitive but visibly dark/black-tinted, unlike
the clear IR emitters.

### IR emitter vs phototransistor — telling them apart

They look almost identical. The **emitter** is clear or faintly blue; the
**phototransistor** is dark grey/black. If you can't tell, a phone camera sees
940 nm as pale violet — power one through a 220 Ω resistor and look at it
through your phone. If it glows on camera, it's the emitter.

### RGB LED — finding the common cathode

The longest leg is *usually* the common, but test:

1. 3.3 V through a 330 Ω resistor.
2. Suspected common → **negative**.
3. Touch the resistor to each of the other three legs.
4. All three light (red, green, blue) → common cathode confirmed, and you've
   just identified which leg is which colour.
5. Nothing lights → you have common **anode**; see below.

**If it's common anode:** tie the common to `3V3` instead of `GND`, and the
firmware logic inverts — `LOW` turns a colour **on**. Everything else is
unchanged.

---

## 8. Resistor values, and why

### IR emitters — 220 Ω

940 nm IR LED forward voltage ≈ 1.3 V.
`(3.3 − 1.3) / 220 Ω = 9 mA`

**Bench-proven at a 40 mm beam gap through PVC pipe.** 9 mA is half the 20 mA a
100 Ω would give, and it works because the pull-down was raised to 100 kΩ at the
same time — sensitivity on the receiver side is cheaper than brightness on the
emitter side, in both current and battery life.

Across two beams that saves ~22 mA per node continuously, which matters on a
supply that has to survive Wi-Fi transmit spikes.

If a cartridge genuinely needs more light, **two 220 Ω in parallel = 110 Ω →
18 mA**. Do not parallel three: 73 Ω gives 27 mA, over the 20 mA continuous
rating of a typical 5 mm IR LED.

### Phototransistor pull-downs — 100 kΩ

Sets sensitivity and edge speed, and this is the value that made the beam work.

At 10 kΩ the pair only triggered with the emitter and phototransistor almost
touching — useless across a pipe. At **100 kΩ** the same parts cleared 40 mm
with margin. That single change was worth more than any amount of emitter
current.

- **Beam never triggers / ball not detected** → the pull-down is too small, or
  the parts are aimed off-axis
- **False triggers, or "implausible speed" in diagnostics** → drop to 10 kΩ
  (crisper edges, less noise pickup) and add emitter current to compensate

> The trade-off: 100 kΩ is sensitive enough to respond to room light and
> sunlight. It is only safe because the beam runs **inside the PVC pipe**, which
> acts as the shroud. A beam mounted in open air needs a proper aperture and
> hood, or a smaller pull-down.

### RGB LED — 330 Ω red, 150 Ω green and blue

Red's forward voltage (~2.0 V) is much lower than green/blue (~3.0 V), so red
needs the bigger resistor or it swamps the others.

`Red:   (3.3 − 2.0) / 330 = 4 mA`
`Green: (3.3 − 3.0) / 150 = 2 mA`

Deliberately modest — this is a battery-powered node, and 20 mA per colour
would be both wasteful and blinding in a dark housing.

**Yellow = red + green together.** Turn both on. If your yellow looks orange,
raise the red resistor to 470 Ω to balance it.

PWM isn't needed for on/off colours, though the ESP32's LEDC peripheral is
there if you later want dimming.

### Battery divider — 100 kΩ / 100 kΩ

Halves the battery voltage so the ADC never sees more than it can take:

| Battery | ADC sees |
|---|---|
| 4.20 V (full) | 2.10 V |
| 3.70 V (nominal) | 1.85 V |
| 3.30 V (empty) | 1.65 V |

Comfortably inside the ESP32's range with 11 dB attenuation. Draw is
`4.2 V / 200 kΩ = 21 µA` — negligible.

The **100 nF cap** across the bottom resistor is not optional. The ESP32's ADC
samples in bursts and its input impedance is not friendly to a 50 kΩ source;
without the cap your readings jump around by 100 mV or more.

---

## 9. Battery thresholds for the RGB LED

A 1S LiPo's voltage is nearly flat through most of its usable charge, then
falls off a cliff. **Don't present it as a percentage** — these four states are
the honest reading. Measured *under load*, so they already include sag.

| State | Voltage | LED | Meaning |
|---|---|---|---|
| `GREEN` | ≥ 3.80 V | Green | Healthy |
| `YELLOW` | 3.65 – 3.80 V | Red + green | Getting low — have a spare ready |
| `RED` | 3.50 – 3.65 V | Red | Swap at the next reset |
| `CRITICAL` | < 3.50 V | **Flashing red** | Minutes from dropping off |

These are the same thresholds the dashboard uses, so the LED on the node and
the battery icon on screen always agree.

### ADC calibration — do this once per board

The ESP32's ADC is **noticeably non-linear** and varies between chips. Don't
trust the raw number:

1. Measure the actual battery voltage with a multimeter at `OUT+`.
2. Read what the firmware reports.
3. `correction = actual / reported`
4. Store that constant per node.

Also **average 16–64 samples** per reading. A single ADC read on an ESP32 is
noisy enough to bounce a node between GREEN and YELLOW.

---

## 10. Build order

Don't build a whole node and then find out. Each stage is testable.

**Stage 1 — power** (do this on one board first)
TP4056 + switch + MT3608, set to 5.0 V, into ESP32 `VIN`. No sensors, no LED.
Success: board boots on battery, existing connection-test firmware reports
ONLINE, and charging works with the switch off.

**Stage 2 — battery sensing**
Add the divider and cap to `D34`. Calibrate against a multimeter.
Success: real voltage in the dashboard instead of grey/UNKNOWN.

**Stage 3 — RGB LED**
Add LED and its three resistors.
Success: colour matches the dashboard's battery icon as the cell drains.

**Stage 4 — one beam**
Beam A cartridge and pull-down only.
Success: blocking the beam with your finger toggles the GPIO.

**Stage 5 — second beam and timing**
Beam B, spaced at your measured `gap_mm`.
Success: rolling a ball through produces a plausible speed on the dashboard.

**Then build the other 19**, from a node you know works.

---

## 11. Do we need a comparator?

Your original notes asked. Short answer: **start without one.**

A phototransistor with a 100 kΩ pull-down gives a usable logic swing, and the
ESP32's inputs have some hysteresis. The firmware state machine handles
debouncing.

An LM393 comparator per beam gives crisper edges and better ambient-light
immunity — but adds a trimpot per beam, which is **40 trimpots to calibrate**
across 20 nodes. That's a real cost.

Build stage 5 without one and watch the troubleshooting panel. If a station
reports **"Implausible speed recorded"** or **"Beam A triggered without beam
B"** repeatedly after you've confirmed alignment, *then* add an LM393 to that
station. The diagnostics were built to make this decision for you with
evidence instead of guesswork.

---

## 12. Common mistakes

| Mistake | Result |
|---|---|
| **MT3608 not pre-set to 5 V** | Up to 28 V into `VIN`. Dead ESP32, instantly |
| **LiPo straight to the `3V3` pin** | 4.2 V on a 3.3 V rail. Damages the ESP32 |
| **LiPo to `VIN` without the boost** | Won't run — regulator has no headroom |
| **TP4056 without protection** | Cell over-discharged and damaged; a safety risk |
| **USB plugged in with the switch ON** | Boost and USB fight over the 5 V rail |
| **Battery JST reversed** | Can vent the cell. Meter it, every time |
| **Using ADC2 pins for battery** | Reads garbage the moment Wi-Fi starts |
| **Using GPIO6–11** | Board won't boot at all |
| **Grounds not all common** | Bizarre intermittent faults that mimic sensor problems |
| **No 100 nF on the ADC** | Battery reading jumps 100 mV+, flickers GREEN/YELLOW |
| **Phototransistor legs swapped** | Beam never triggers. Test before soldering |
| **Forgetting `gap_mm`** | Every speed from that station is silently wrong |

---

## 13. The one measurement that matters

`gap_mm` — the distance between beam A and beam B — is the number every
velocity depends on:

```
speed = gap_mm / Δt
```

**Measure it on the built cartridge, not from the CAD model.** A 2 mm error
over a 100 mm gap is a 2% error on every reading that station ever produces,
and nothing in the system can detect it.

Record it per station in `config/nodes.json`, and put the same value in that
node's firmware.

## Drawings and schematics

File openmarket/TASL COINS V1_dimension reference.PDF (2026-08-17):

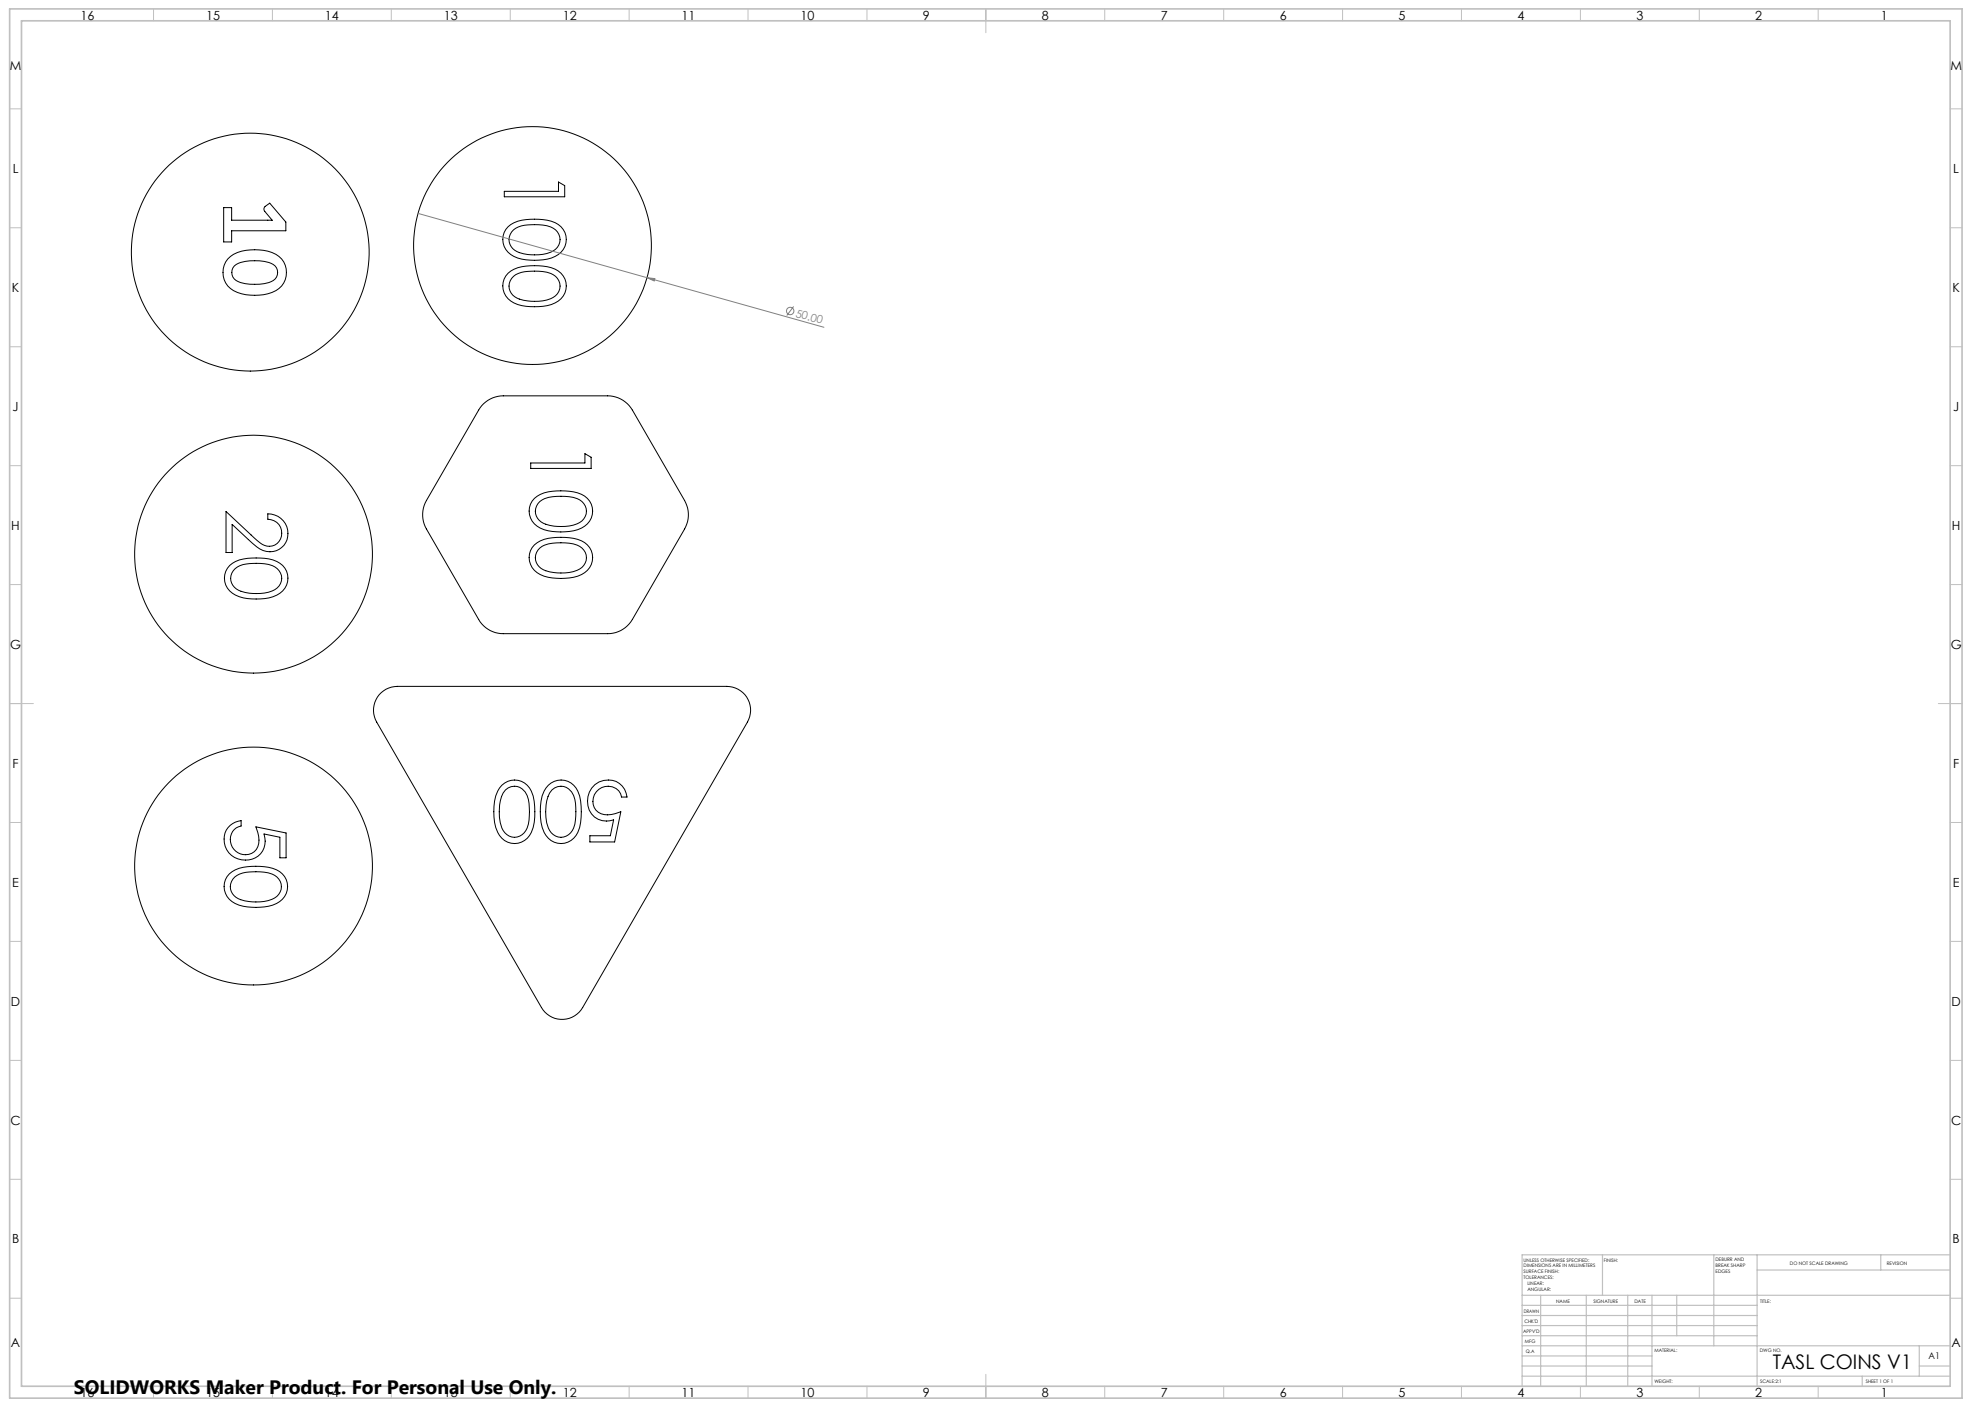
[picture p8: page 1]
FINISH:; DEBURR AND; BREAK SHARP; DO NOT SCALE DRAWING; REVISION; SCALE:2:1; SHEET 1 OF 1

UNLESS OTHERWISE SPECIFIED:
DIMENSIONS ARE IN MILLIMETERS
SURFACE FINISH:
TOLERANCES:
LINEAR:
ANGULAR:

NAME | SIGNATURE | DATE | | | | TITLE:

DRAWN
CHK'D
APPV'D
MFG
Q.A | | | | MATERIAL: | DWG NO. TASL COINS V1 | A1

SOLIDWORKS Maker Product. For Personal Use Only.

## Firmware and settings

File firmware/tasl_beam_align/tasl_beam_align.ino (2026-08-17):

/* ============================================================================
   TASL - IR BEAM ALIGNMENT / BREAK TEST
   Board: ESP32 DevKit V1

   Standalone bench tool. No Wi-Fi, no battery, no dashboard.
   Flash it, open Serial Monitor at 115200, break the beam.

   Wiring per beam:
     3V3 --[220R]--> IR emitter --> GND        (long leg = anode)
     3V3 ----------- phototransistor collector
                     emitter --+-- [10k] -- GND
                               +-- GPIO

   Beam clear   -> phototransistor conducts -> pin HIGH
   Beam blocked -> phototransistor off      -> 10k pulls it LOW
   ========================================================================= */

#define BEAMS         1      // 1 or 2

#define PIN_BEAM_A    19
#define PIN_BEAM_B    18

// Set to 1 ONLY if the pin above is ADC1 (GPIO32-39). Gives a raw 0-4095
// level, which is better for fine aiming. Any other pin must stay at 0.
#define BEAM_ANALOG   0

#define PRINT_MS      500

int  breaksA = 0, breaksB = 0;
bool lastA = true, lastB = true;
int  rawMinA = 4095, rawMaxA = 0;
int  rawMinB = 4095, rawMaxB = 0;

void setup() {
  Serial.begin(115200);
  delay(400);

  // No INPUT_PULLUP: the 10k pull-down sets the idle level. An internal
  // pull-up would fight it and hold the pin high permanently, which looks
  // exactly like a beam that never triggers.
  pinMode(PIN_BEAM_A, INPUT);
#if BEAMS > 1
  pinMode(PIN_BEAM_B, INPUT);
#endif

#if BEAM_ANALOG
  analogReadResolution(12);
  analogSetPinAttenuation(PIN_BEAM_A, ADC_11db);
  #if BEAMS > 1
    analogSetPinAttenuation(PIN_BEAM_B, ADC_11db);
  #endif
#endif

  Serial.println();
  Serial.println("=============================");
  Serial.println(" TASL beam break test");
  Serial.printf ("  beam A on GPIO%d\n", PIN_BEAM_A);
#if BEAMS > 1
  Serial.printf ("  beam B on GPIO%d\n", PIN_BEAM_B);
#endif
  Serial.println("=============================");
  Serial.println("Put a finger through the beam.");
  Serial.println("Send 'r' to reset counters.");
  Serial.println();
}

// Reports one beam. Prints a line on every state CHANGE (that is the thing
// you are testing), plus a periodic status line so you can see it is alive.
void checkBeam(const char* name, uint8_t pin, bool& last, int& breaks,
               int& rawMin, int& rawMax) {
  bool clear;
  int  raw = -1;

#if BEAM_ANALOG
  uint32_t sum = 0;
  for (int i = 0; i < 8; i++) { sum += analogRead(pin); delayMicroseconds(200); }
  raw   = sum / 8;
  clear = raw > 2048;
  if (raw < rawMin) rawMin = raw;
  if (raw > rawMax) rawMax = raw;
#else
  clear = digitalRead(pin) == HIGH;
#endif

  if (clear != last) {
    last = clear;
    if (!clear) {
      breaks++;
      Serial.printf(">>> beam %s BROKEN   (break #%d)\n", name, breaks);
    } else {
      Serial.printf("    beam %s clear\n", name);
    }
  }
}

void status(const char* name, uint8_t pin, int breaks, int rawMin, int rawMax) {
#if BEAM_ANALOG
  int span = rawMax - rawMin;
  Serial.printf("beam %s: %-7s raw range %4d..%4d span=%4d  breaks=%d\n",
                name, digitalRead(pin) ? "CLEAR" : "BLOCKED",
                rawMin, rawMax, span, breaks);
#else
  Serial.printf("beam %s: %-7s  breaks=%d\n",
                name, digitalRead(pin) == HIGH ? "CLEAR" : "BLOCKED", breaks);
#endif
}

unsigned long lastPrint = 0;

void loop() {
  if (Serial.available() && Serial.read() == 'r') {
    breaksA = breaksB = 0;
    rawMinA = rawMinB = 4095;
    rawMaxA = rawMaxB = 0;
    Serial.println("-- counters reset --");
  }

  // Polled fast so a quick hand wave is not missed.
  checkBeam("A", PIN_BEAM_A, lastA, breaksA, rawMinA, rawMaxA);
#if BEAMS > 1
  checkBeam("B", PIN_BEAM_B, lastB, breaksB, rawMinB, rawMaxB);
#endif

  unsigned long now = millis();
  if (now - lastPrint >= PRINT_MS) {
    lastPrint = now;
    status("A", PIN_BEAM_A, breaksA, rawMinA, rawMaxA);
#if BEAMS > 1
    status("B", PIN_BEAM_B, breaksB, rawMinB, rawMaxB);
#endif
  }

  delay(2);
}

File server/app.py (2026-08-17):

"""
TASL laptop server.

Two audiences:
  - ESP32 nodes, which POST JSON to /api/heartbeat and /api/event
  - the browser screens, which load a page and then listen on /ws

Four screens, one server, one WebSocket. Everything is in sync because there
is only ever one copy of the state:

  /         ball location and speed      MiniPC by the build space
  /depot    live BOM prices              MiniPC at the materials depot
  /stage    breaking-news projector      laptop on stage
  /admin    triggers + diagnostics       MiniPC with the operator

There are no logins. The screens are separated by URL, and the diagnostics
that used to sit behind a wrench icon on the public dashboard now live only
on /admin, so participants never see a station misbehaving.

Run it with:   python run_server.py
"""

from __future__ import annotations

import asyncio
import contextlib
import json
from pathlib import Path
from typing import Any

from fastapi import Body, FastAPI, WebSocket, WebSocketDisconnect
from fastapi.responses import FileResponse, JSONResponse
from fastapi.staticfiles import StaticFiles

from server.diagnostics import diagnose_all
from server.protocol import Heartbeat, NodeEvent
from server.store import Store

STATIC_DIR = Path(__file__).resolve().parent / "static"

store = Store()


SCREEN_ROLES = ("live", "depot", "stage", "admin")


class Hub:
    """Keeps the set of connected browsers and fans messages out to them."""

    def __init__(self) -> None:
        # ws -> role. Each page says what it is on connect, which is how the
        # admin panel can answer "is the projector actually still plugged in"
        # without anyone walking across the hall to look at it.
        self._clients: dict[WebSocket, str] = {}
        self._lock = asyncio.Lock()

    async def join(self, ws: WebSocket) -> None:
        await ws.accept()
        async with self._lock:
            self._clients[ws] = "unknown"

    async def leave(self, ws: WebSocket) -> None:
        async with self._lock:
            self._clients.pop(ws, None)

    async def set_role(self, ws: WebSocket, role: str) -> None:
        async with self._lock:
            if ws in self._clients:
                self._clients[ws] = role if role in SCREEN_ROLES else "unknown"

    def screens(self) -> dict[str, int]:
        """How many browsers of each kind are currently connected."""
        counts = {role: 0 for role in SCREEN_ROLES}
        counts["unknown"] = 0
        for role in self._clients.values():
            counts[role] = counts.get(role, 0) + 1
        return counts

    async def broadcast(self, message: dict[str, Any]) -> None:
        payload = json.dumps(message)
        async with self._lock:
            targets = list(self._clients.keys())
        dead: list[WebSocket] = []
        for ws in targets:
            try:
                await ws.send_text(payload)
            except Exception:
                # A browser tab closed mid-send. Not an error worth logging at
                # an event; just drop it.
                dead.append(ws)
        if dead:
            async with self._lock:
                for ws in dead:
                    self._clients.pop(ws, None)


hub = Hub()


async def _push_screens() -> None:
    await hub.broadcast({"type": "screens", "screens": hub.screens()})


async def _offline_watchdog() -> None:
    """Once a second, demote silent nodes to OFFLINE and tell the browsers."""
    while True:
        try:
            for node in store.sweep_offline():
                await hub.broadcast({"type": "node", "node": node.to_dict()})
        except Exception as exc:  # never let the watchdog die
            print(f"[watchdog] {exc!r}")
        await asyncio.sleep(1.0)


@contextlib.asynccontextmanager
async def lifespan(app: FastAPI):
    task = asyncio.create_task(_offline_watchdog())
    yield
    task.cancel()
    with contextlib.suppress(asyncio.CancelledError):
        await task


app = FastAPI(title="TASL Marble Run", lifespan=lifespan)


@app.middleware("http")
async def no_store(request, call_next):
    """
    Nothing this server sends is ever worth caching.

    Four machines run this in kiosk mode for a whole day. When something is
    edited and a screen is reloaded, it must come back with the edit - "I
    changed it and nothing happened" is not a puzzle anyone should be solving
    twenty minutes before the event starts. There is no bandwidth argument
    against it: everything is local and measured in kilobytes.
    """
    response = await call_next(request)
    response.headers["Cache-Control"] = "no-store"
    return response


# ----------------------------------------------------------------- node API

@app.post("/api/heartbeat")
async def post_heartbeat(hb: Heartbeat) -> JSONResponse:
    node = store.apply_heartbeat(hb)
    if node is None:
        # Unknown node. Tell the ESP32 clearly rather than silently accepting -
        # a typo'd node_id is otherwise invisible until event day.
        return JSONResponse(
            {"ok": False, "error": f"unknown node_id '{hb.node_id}' - add it to config/nodes.json"},
            status_code=404,
        )
    await hub.broadcast({"type": "node", "node": node.to_dict()})
    return JSONResponse({"ok": True})


@app.post("/api/event")
async def post_event(ev: NodeEvent) -> JSONResponse:
    node, record = store.apply_event(ev)
    if node is None or record is None:
        return JSONResponse(
            {"ok": False, "error": f"unknown node_id '{ev.node_id}' - add it to config/nodes.json"},
            status_code=404,
        )
    await hub.broadcast(
        {
            "type": "event",
            "node": node.to_dict(),
            "event": record,
            "run": store.run_dict(),
        }
    )
    return JSONResponse({"ok": True})


# ------------------------------------------------------------ dashboard API

@app.get("/api/state")
async def get_state() -> dict[str, Any]:
    return store.snapshot()


@app.get("/api/diagnostics")
async def get_diagnostics() -> dict[str, Any]:
    """
    Computed fresh on request rather than pushed. The browser polls this every
    couple of seconds while the Diagnostics tab is relevant - far simpler than
    recomputing and broadcasting the whole rule set on every packet, and with
    20 nodes it costs nothing.
    """
    return diagnose_all(list(store.nodes.values()))


@app.post("/api/diagnostics/clear")
async def clear_diagnostics() -> dict[str, Any]:
    """Zero the health counters, for use after physically fixing something."""
    store.clear_diagnostics()
    snap = store.snapshot()
    await hub.broadcast(snap)
    return diagnose_all(list(store.nodes.values()))


@app.post("/api/run/start")
async def run_start() -> dict[str, Any]:
    run = store.start_run()
    await hub.broadcast({"type": "run", "run": run})
    return run
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

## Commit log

2026-08-17 Initial commit: TASL marble-run sensing and dashboard system
    Live monitoring for a modular marble-run engineering challenge. ESP32 nodes
    watch a 25 mm steel ball with IR break-beams, time it on-node, and report to
    a laptop dashboard over an offline Wi-Fi network.
    Software
    - FastAPI server with WebSocket dashboard and SQLite event log
    - Diagnostics engine: per-node fault rules with ordered physical checks
    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
    [Assem1.SLDASM, Bottom case.SLDPRT, Bottom case.STL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]
2026-08-17 Depot/stage/admin market screens, driven by the final BOM
    Adds the three event-day screens that were missing and wires them to the
    real materials list.
    GamePlan is now in the repo under docs/gameplan/ - the master BOM, the
    economy and sizing notes, the machine-readable data and the printed team
    guide book. It is the source of truth: config/market.json is generated
    from it, never the other way round.
    The market:
    - 34 sellable lines with the BOM's exact names, ids, base prices, buyback
    and stock counts, in the BOM's six groups. Balls stay facilitator-only.
    - Currency is Kasu.
    - Price math now COMPOUNDS and rounds UP after each event, replacing the
    additive model. War +20 then Tariff +30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
    [app.py, market.py, store.py]
